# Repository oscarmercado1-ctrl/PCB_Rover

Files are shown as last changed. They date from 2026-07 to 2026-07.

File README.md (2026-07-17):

# Diseño de PCB basada en FPGA para Robot Móvil Autónomo

## Descripción

Este proyecto corresponde al diseño electrónico de una plataforma robótica móvil desarrollada como parte del curso **Diseño de Productos Electrónicos** de la **Universidad de Antioquia**.

El objetivo fue diseñar una PCB multicapa basada en una FPGA **Digilent CMOD A7 (Artix-7)** capaz de integrar sensores, actuadores, comunicaciones inalámbricas y sistemas de navegación en una arquitectura modular y escalable.

El desarrollo incluye el diseño completo del esquemático, captura jerárquica, reglas de diseño (DRC), generación del PCB de cuatro capas, análisis de costos y documentación técnica del proyecto.

---

# Características principales

- Diseño de PCB de **4 capas**.
- Arquitectura basada en FPGA **Xilinx Artix-7**.
- Comunicación inalámbrica mediante **LoRa SX1276**.
- Sistema de posicionamiento **GNSS (u-blox NEO-M9N)**.
- Sensores ambientales, inerciales y de presión.
- Comunicación mediante:
  - SPI
  - I²C
  - UART
- Control de:
  - Motores DC
  - Servomotores
  - Motor paso a paso
- Interfaz para pantalla LCD.
- Sistema de alimentación unificado a **3.3 V**.

---

# Arquitectura del sistema

La FPGA actúa como unidad central de procesamiento, implementando de forma concurrente:

- Comunicación LoRa
- Comunicación GNSS
- Lectura de sensores
- Control de motores
- Generación de señales PWM
- Procesamiento de encoders
- Gestión de la interfaz de usuario

Todo el sistema fue diseñado utilizando una arquitectura modular mediante hojas jerárquicas en Altium Designer.

---

# Componentes principales

| Componente | Función |
|---|---|
| Digilent CMOD A7 (Artix-7) | Unidad de procesamiento |
| SX1276 | Comunicación LoRa |
| u-blox NEO-M9N | Posicionamiento GNSS |
| MPU-6050 | IMU |
| Magnetómetro | Orientación |
| ADS1115 | Conversor ADC |
| Sensores de presión Honeywell MPRLS | Medición de presión |
| Encoders ópticos TCST2103 | Velocidad de motores |
| Drivers A4988 | Motor paso a paso |
| Driver L298N | Motores DC |

---

# Diseño de la PCB

El PCB fue desarrollado considerando criterios profesionales de diseño electrónico:

- PCB de cuatro capas
- Plano de tierra continuo
- Plano de alimentación dedicado
- Separación entre dominios:
  - Radiofrecuencia
  - Potencia
  - Lógica digital
- Capacitores de desacople próximos a cada circuito integrado
- Impedancia controlada para líneas RF
- Reglas de diseño compatibles con fabricantes comerciales

---

# Herramientas utilizadas

- Altium Designer
- Altium 365
- GitHub
- LaTeX
- Microsoft Excel

---

# Archivos incluidos

- Proyecto completo de Altium Designer.
- Librerías personalizadas.
- Esquemáticos jerárquicos.
- Diseño del PCB.
- Bill of Materials (BOM).
- Archivos Gerber.
- Informe técnico.
- Documentación del proyecto.

---

# Objetivos del diseño

- Integrar múltiples sensores sobre una única plataforma.
- Implementar procesamiento concurrente mediante FPGA.
- Garantizar comunicaciones inalámbricas de largo alcance.
- Facilitar futuras expansiones del sistema.
- Cumplir criterios profesionales de manufactura de PCB.

---

# Fabricación

La PCB fue diseñada para fabricación en proveedores comerciales como:

- JLCPCB
- PCBWay
- OSH Park

Características:

- 4 capas
- Espesor: 1.6 mm
- Cobre: 1 oz
- Acabado HASL libre de plomo
- Vías mínimas: 0.20 mm
- Separación mínima: 0.15 mm

---

# Autores

**Oscar David Mercado Gómez**

**Carlos Daniel Galvis Ramirez**

Ingeniería Electrónica  
Universidad de Antioquia

---

# Licencia

Este proyecto fue desarrollado con fines académicos como parte del curso **Diseño de Productos Electrónicos** de la Universidad de Antioquia.

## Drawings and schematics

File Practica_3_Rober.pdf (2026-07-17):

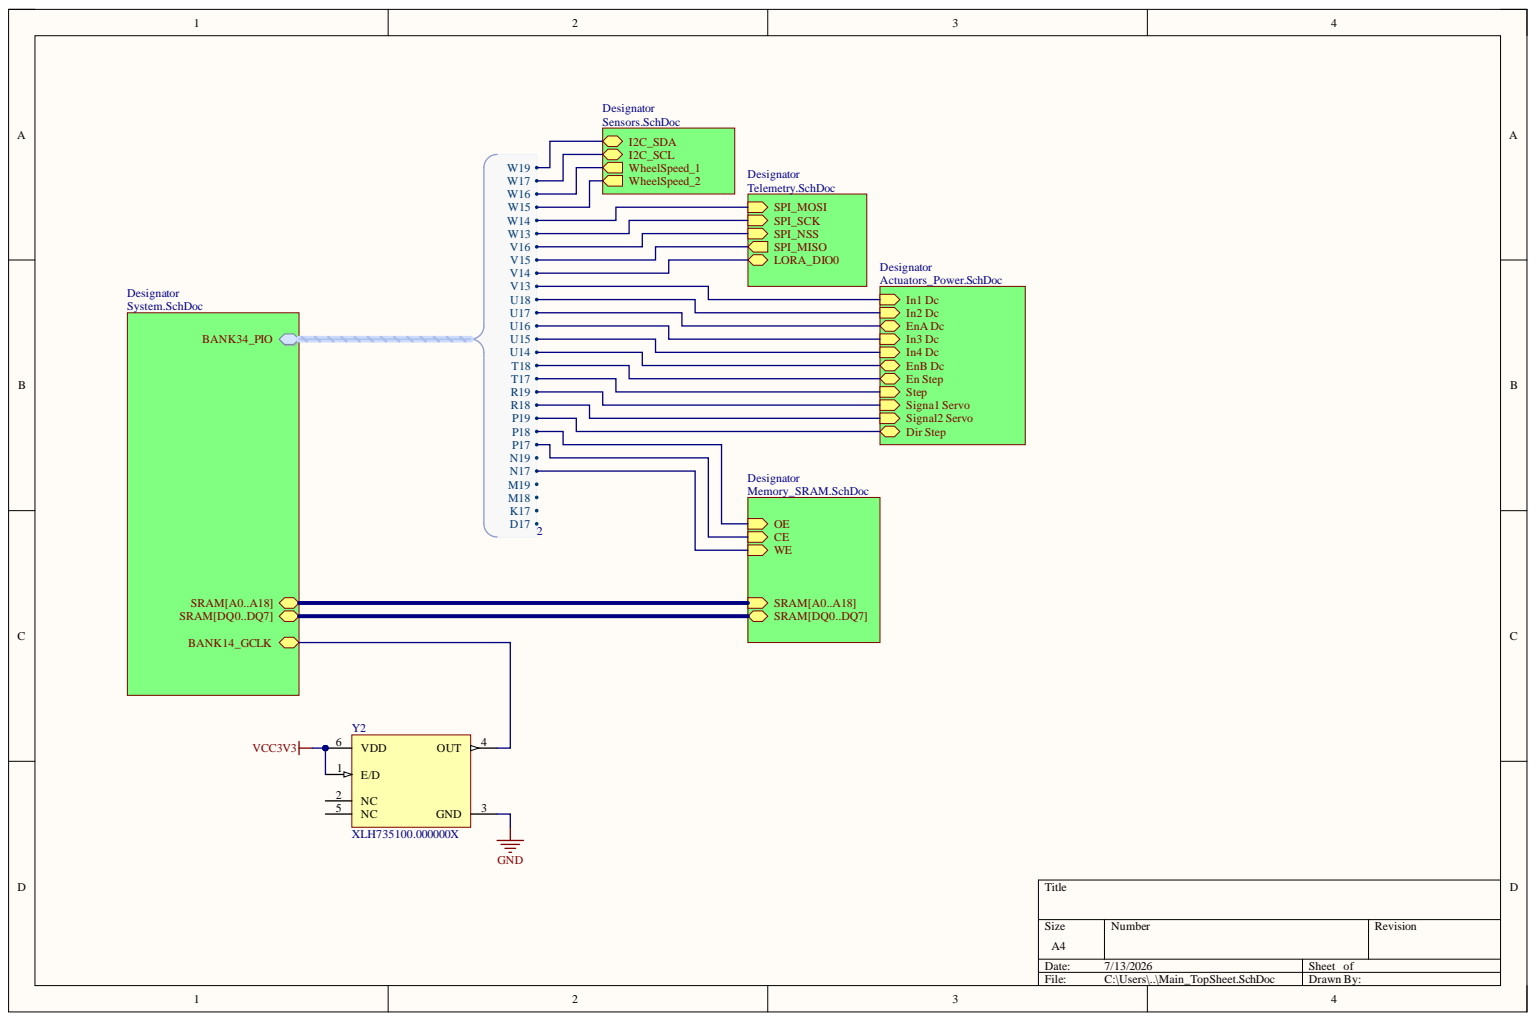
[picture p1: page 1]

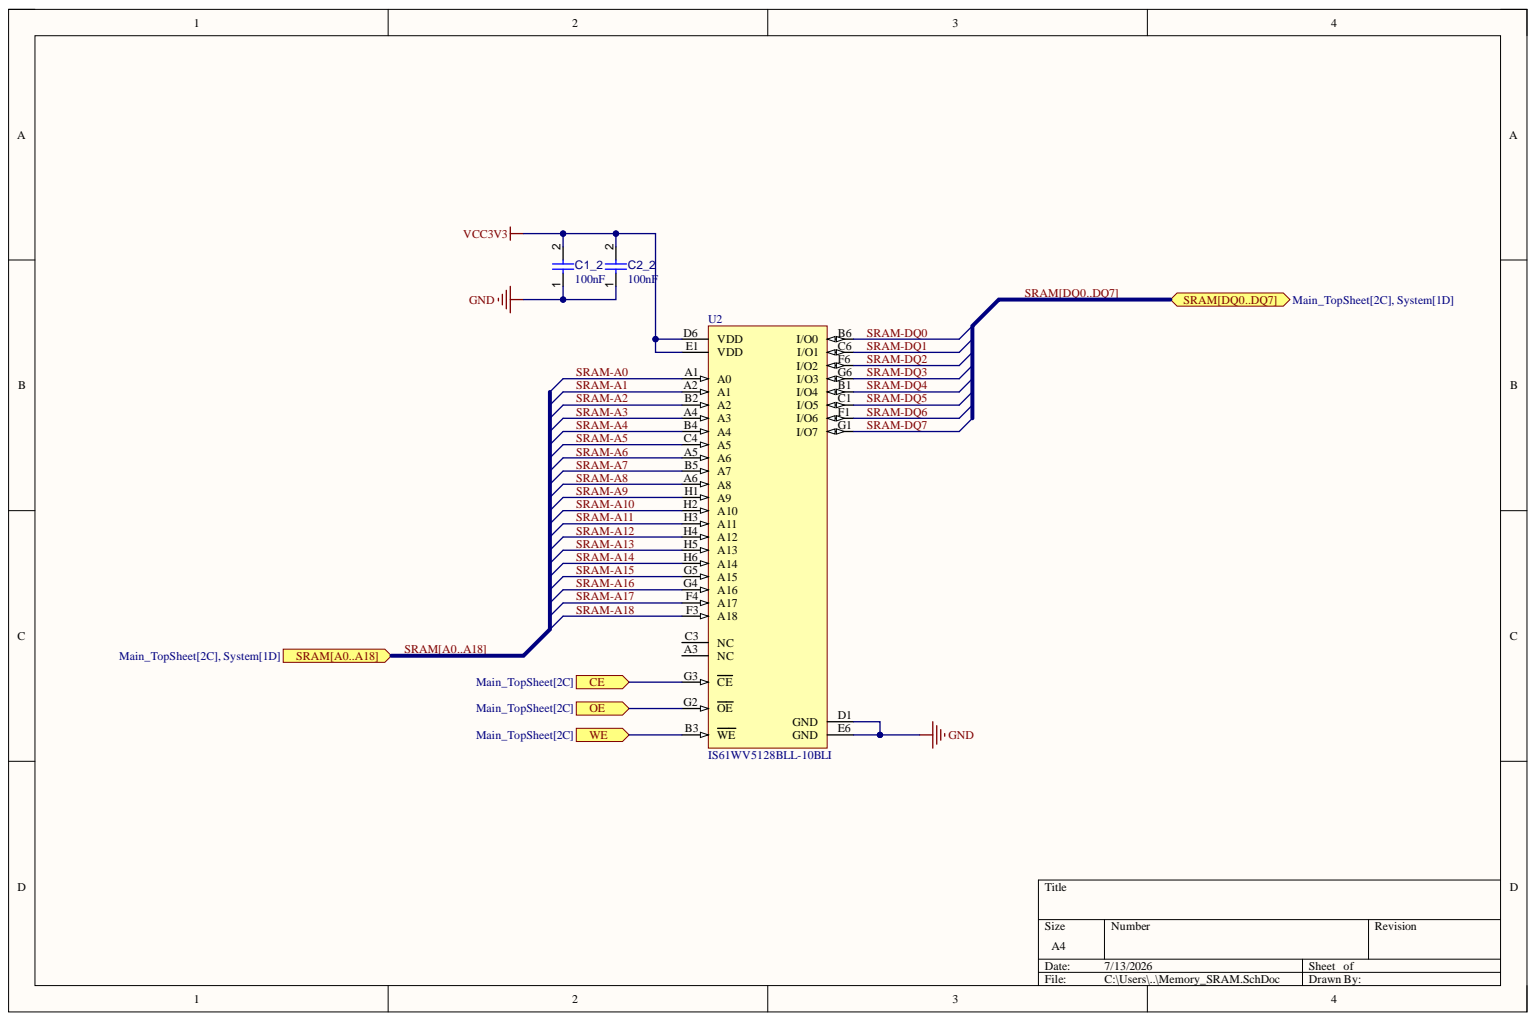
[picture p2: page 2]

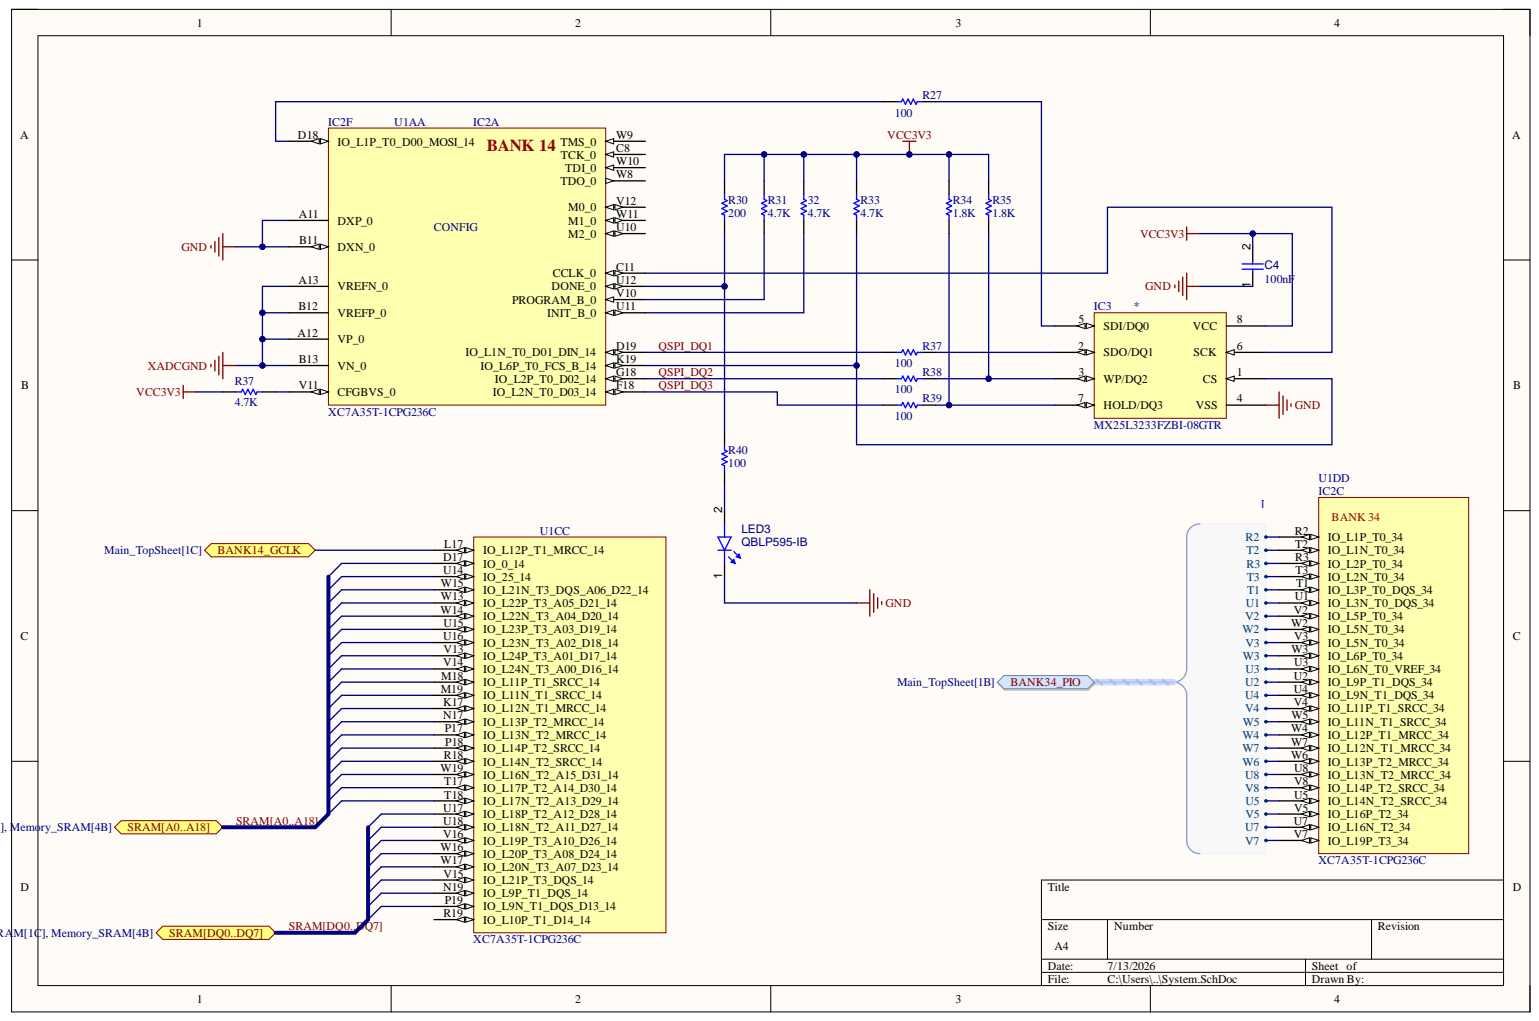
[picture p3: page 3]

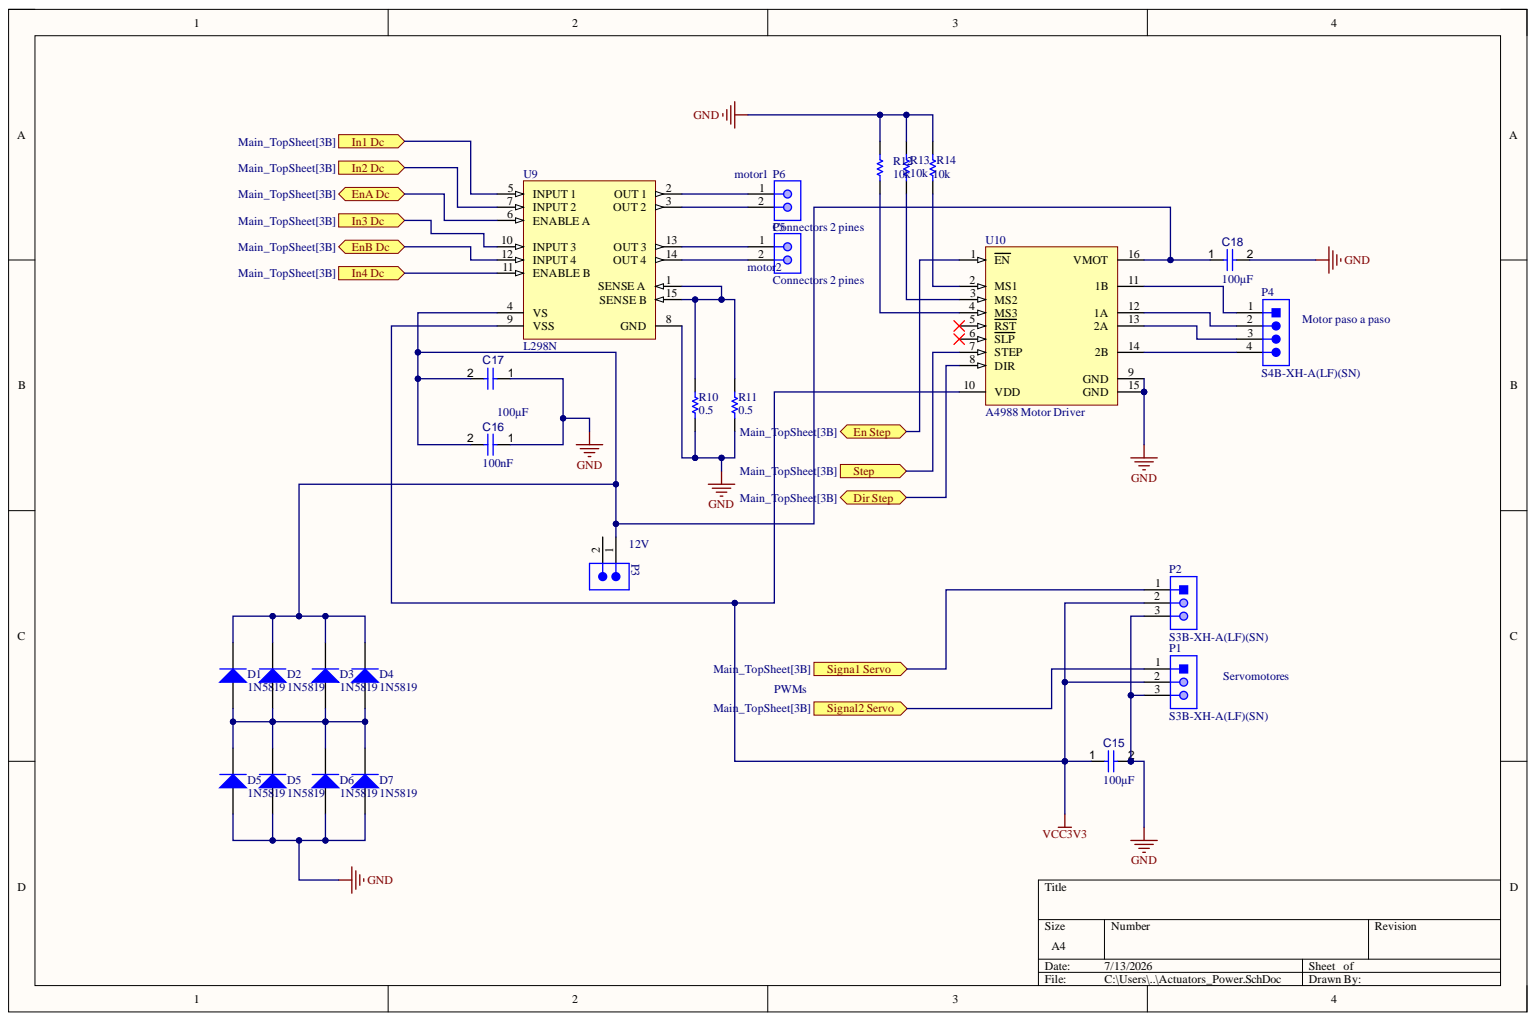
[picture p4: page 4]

MS3 4
RST 5 | 2

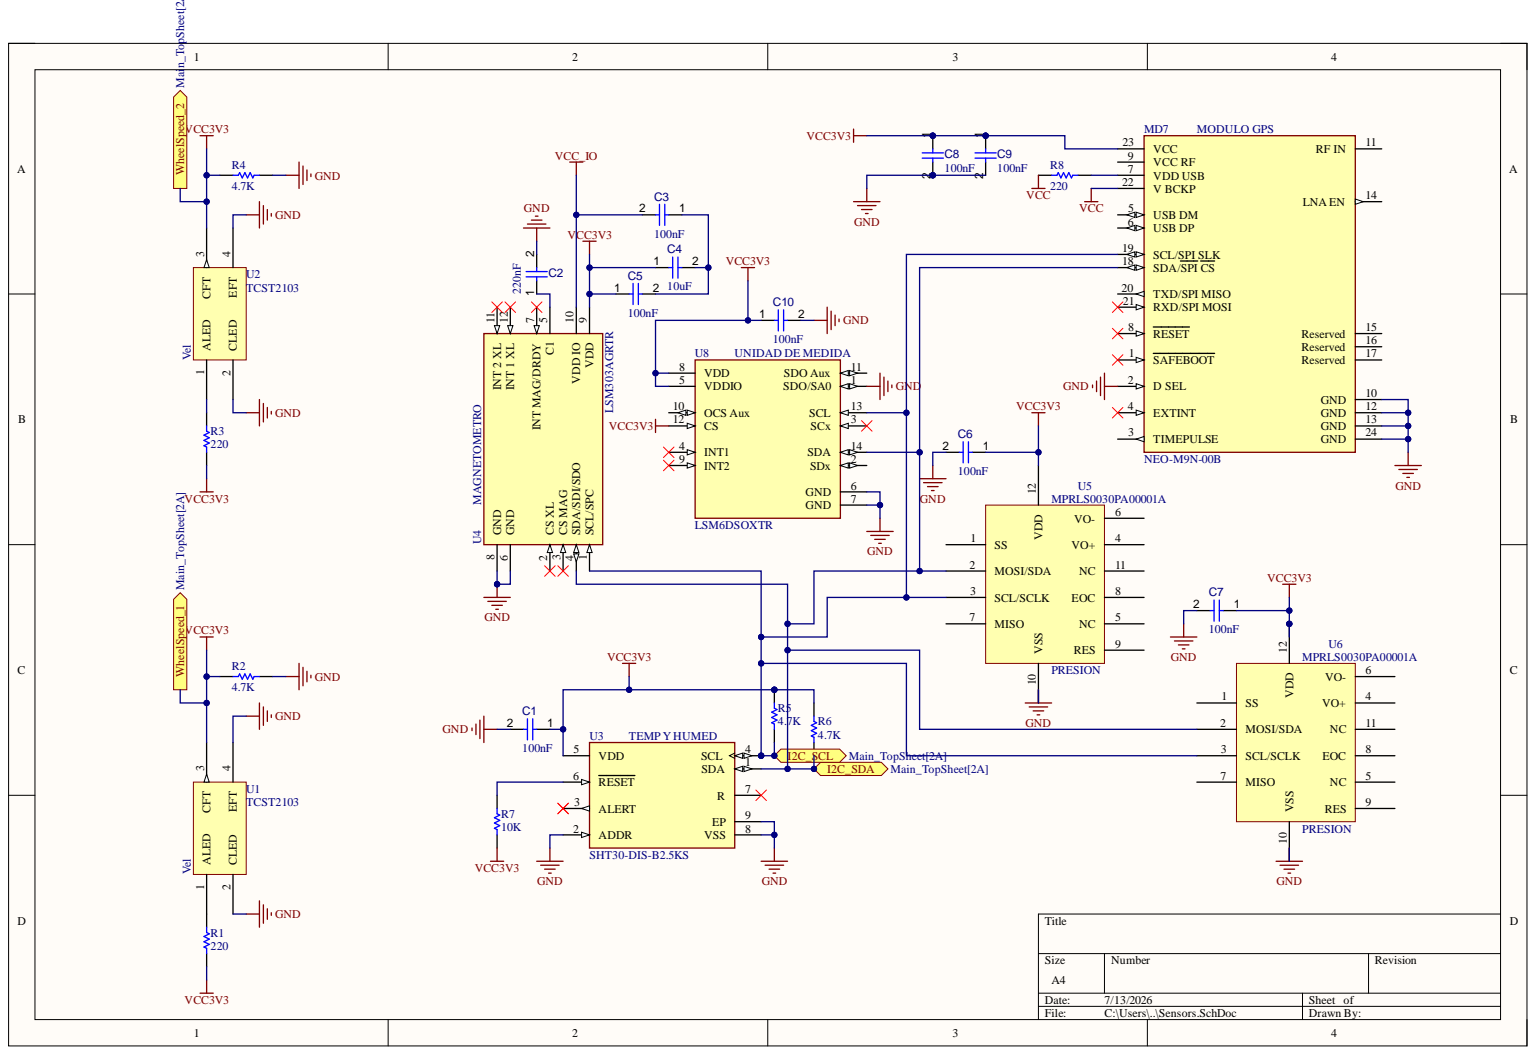
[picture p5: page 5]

INT 1 XL 12 INT 2 XL 11

VDD 9 VDD IO 10 CS MAG 3 CS XL 2

SCL/SPC 1 SDA/SDI/SDO 4

3 | MOSI/SD A N C SCL/SCL K E O C | 8

7 | MISO N C RE S

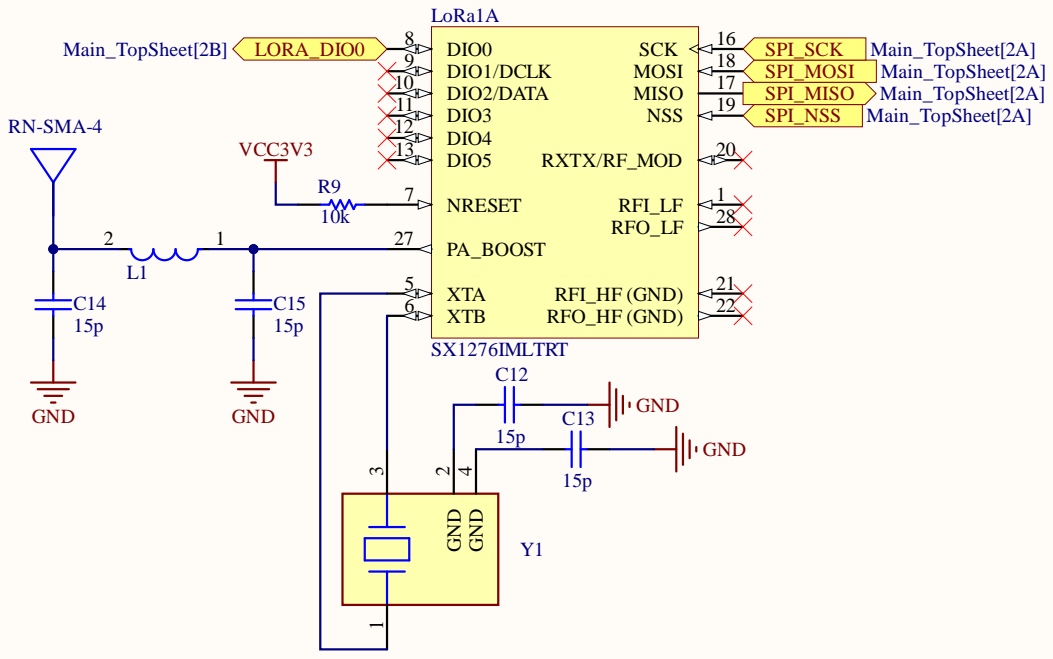
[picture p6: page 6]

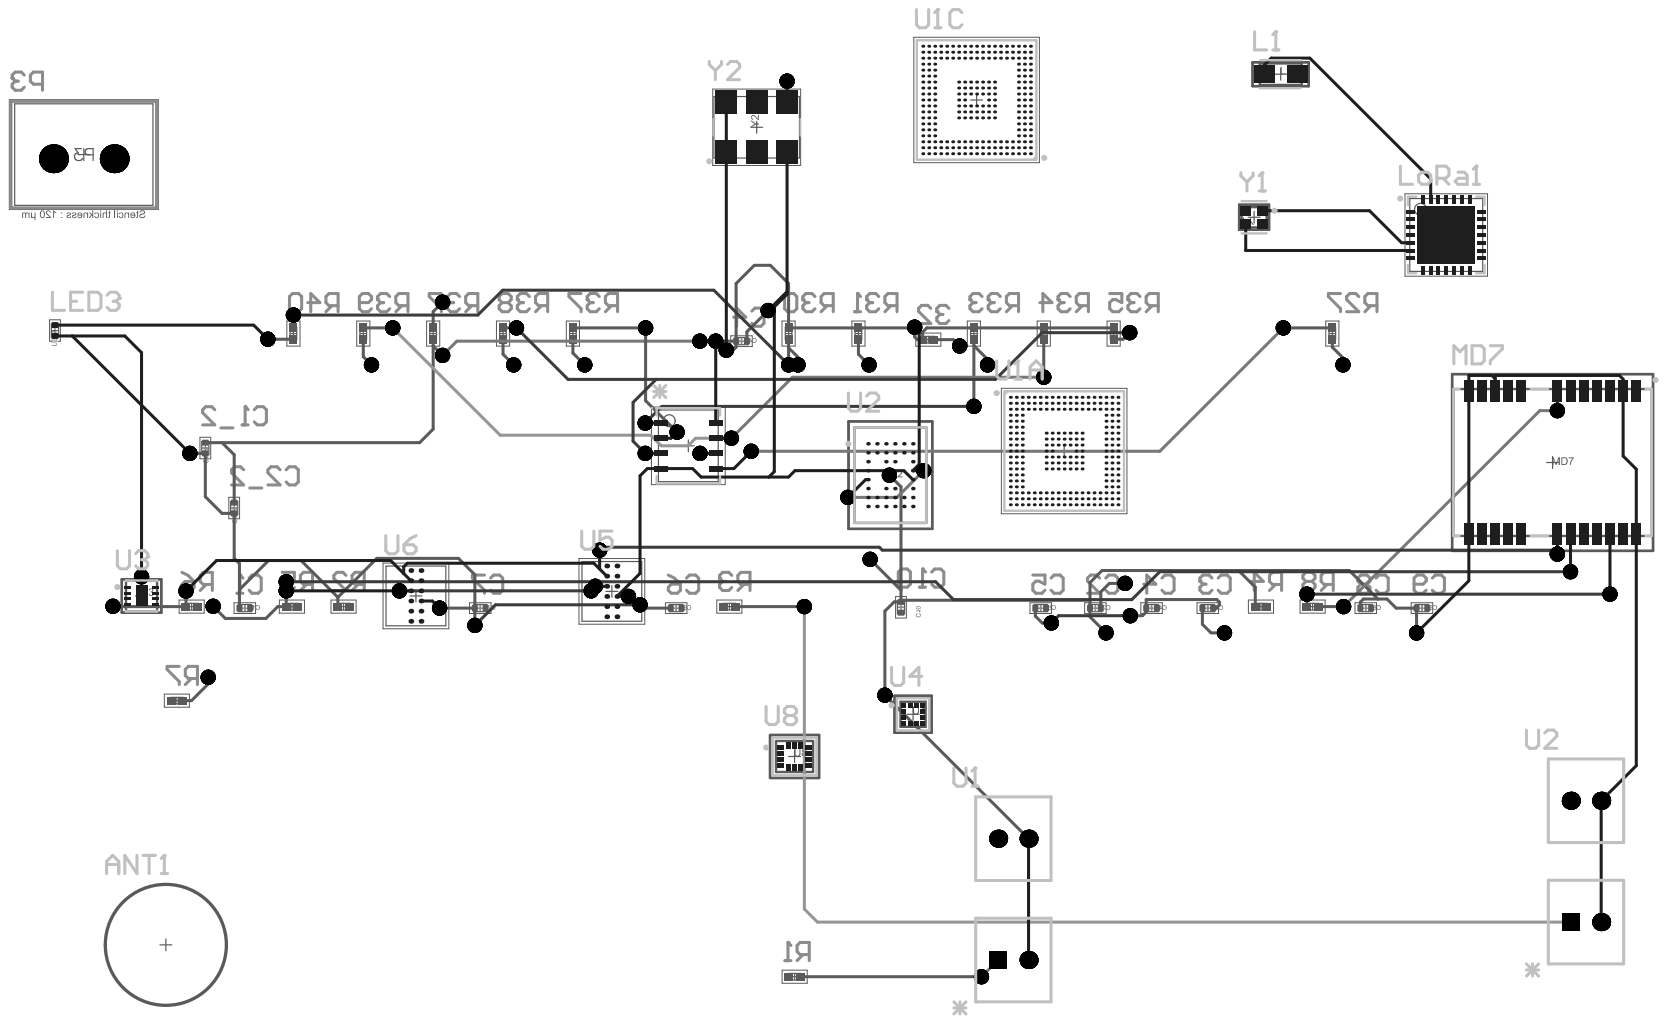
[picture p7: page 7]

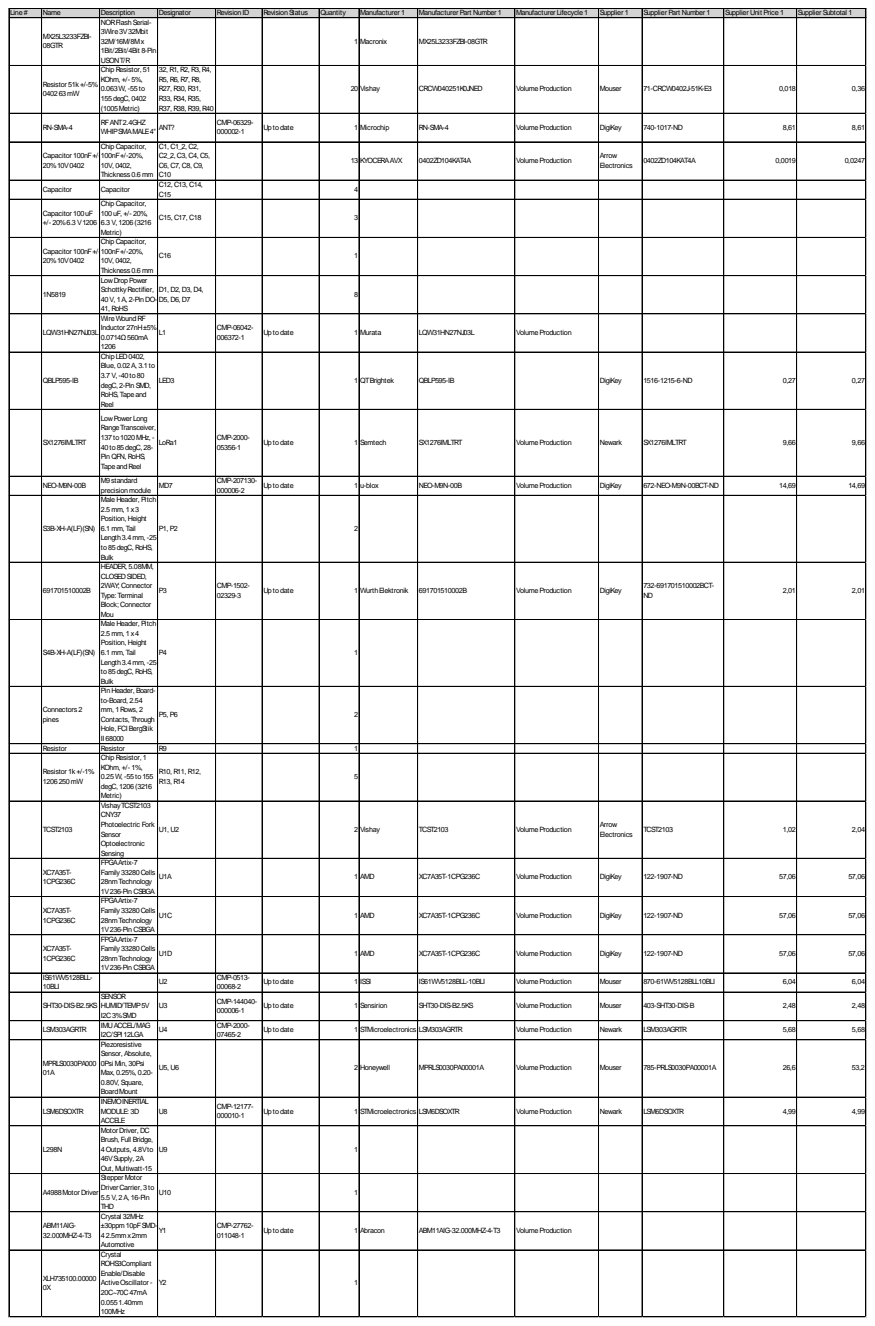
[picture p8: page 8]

Line# | Name | Description | Designator | RevisionID | RevisionStatus | Quantity | Manufacturer 1 | Manufacturer Part Number 1 | Manufacturer Lifecycle 1 | Supplier 1 | Supplier Part Number 1 | Supplier Unit Price 1 | Supplier Subtotal 1

MX25L3233FZBI-08GTR | NORFlashSerial-3Wire3V32Mbit 32M/16M/8Mx 1Bit/2Bit/4Bit 8-Pin USONT/R | | | | | 1 Macronix | MX25L3233FZBI-08GTR

Resistor 51k+/-5% 040263mW | Chip Resistor, 51 KOhm, +/- 5%, 0.063W, -55to 155degC, 0402 (1005Metric) | 32, R1, R2, R3, R4, R5, R6, R7, R8, R27, R30, R31, R33, R34, R35, R37, R38, R39, R40 | | | 20 Vishay | | CRCW040251K0JNED | VolumeProduction | Mouser | 71-CRCW0402J-51K-E3 | 0,018 | 0,36

RN-SMA-4 | RFANT2.4GHZ WHIPSMAMALE4" | ANT? | CMP-06329-000002-1 | Uptodate | | 1 Microchip | RN-SMA-4 | VolumeProduction | DigiKey | 740-1017-ND | 8,61 | 8,61

Capacitor 100nF+/-20%10V0402 | Chip Capacitor, 100nF+/-20%, 10V, 0402, Thickness0.6 mm | C1, C1_2, C2, C2_2, C3, C4, C5, C6, C7, C8, C9, C10 | | | 13 KYOCERAAVX | | 0402ZD104KAT4A | VolumeProduction | Arrow Electronics | 0402ZD104KAT4A | 0,0019 | 0,0247

Capacitor | Capacitor | C12, C13, C14, C15 | | | | 4

Capacitor 100uF +/- 20%6.3V1206 | Chip Capacitor, 100uF, +/- 20%, 6.3V, 1206(3216 Metric) | C15, C17, C18 | | | | 3

Capacitor 100nF+/-20%10V0402 | Chip Capacitor, 100nF+/-20%, 10V, 0402, Thickness0.6 mm | C16 | | | | 1

1N5819 | LowDropPower SchottkyRectifier, 40V, 1A, 2-Pin DO-41, RoHS | D1, D2, D3, D4, D5, D6, D7 | | | | 8

LQW31HN27NJ03L | WireWoundRF Inductor 27nH±5% 0.0714Ω560mA 1206 | L1 | CMP-06042-006372-1 | Uptodate | | 1 Murata | LQW31HN27NJ03L | VolumeProduction

QBLP595-IB | ChipLED0402, Blue, 0.02A, 3.1 to 3.7V, -40to80 degC, 2-PinSMD, RoHS, Tapeand Reel | LED3 | | | | 1 QTBrightek | QBLP595-IB | | DigiKey | 1516-1215-6-ND | 0,27 | 0,27

SX1276IMLTRT | LowPower Long RangeTransceiver, 137to1020MHz, -40to85degC, 28-Pin QFN, RoHS, TapeandReel | LoRa1 | CMP-2000-05356-1 | Uptodate | | 1 Semtech | SX1276IMLTRT | VolumeProduction | Newark | SX1276IMLTRT | 9,66 | 9,66

NEO-M9N-00B | M9standard precisionmodule | MD7 | CMP-207130-000006-2 | Uptodate | | 1 u-blox | NEO-M9N-00B | VolumeProduction | DigiKey | 672-NEO-M9N-00BCT-ND | 14,69 | 14,69

S3B-XH-A(LF)(SN) | Male Header, Pitch 2.5 mm, 1x3 Position, Height 6.1 mm, Tail Length3.4 mm, -25 to85degC, RoHS, Bulk | P1, P2 | | | | 2

691701510002B | HEADER, 5.08MM, CLOSEDSIDED, 2WAY; Connector Type: Terminal Block; Connector Mou | P3 | CMP-1502-02329-3 | Uptodate | | 1 WurthElektronik | 691701510002B | VolumeProduction | DigiKey | 732-691701510002BCT-ND | 2,01 | 2,01

S4B-XH-A(LF)(SN) | Male Header, Pitch 2.5 mm, 1x4 Position, Height 6.1 mm, Tail Length3.4 mm, -25 to85degC, RoHS, Bulk | P4 | | | | 1

Connectors2 pines | PinHeader, Board-to-Board, 2.54 mm, 1Rows, 2 Contacts, Through Hole, FCIBergStik II68000 | P5, P6 | | | | 2

Resistor | Resistor | R9 | | | | 1
Resistor 1k+/-1% 1206250mW | Chip Resistor, 1 KOhm, +/- 1%, 0.25W, -55to155 degC, 1206(3216 Metric) | R10, R11, R12, R13, R14 | | | | 5

TCST2103 | VishayTCST2103 CNY37 Photoelectric Fork Sensor Optoelectronic Sensing | U1, U2 | | | | 2 Vishay | TCST2103 | VolumeProduction | Arrow Electronics | TCST2103 | 1,02 | 2,04

XC7A35T-1CPG236C | FPGAArtix-7 Family 33280Cells 28nmTechnology 1V236-Pin CSBGA | U1A | | | | 1 AMD | XC7A35T-1CPG236C | VolumeProduction | DigiKey | 122-1907-ND | 57,06 | 57,06

XC7A35T-1CPG236C | FPGAArtix-7 Family 33280Cells 28nmTechnology 1V236-Pin CSBGA | U1C | | | | 1 AMD | XC7A35T-1CPG236C | VolumeProduction | DigiKey | 122-1907-ND | 57,06 | 57,06

XC7A35T-1CPG236C | FPGAArtix-7 Family 33280Cells 28nmTechnology 1V236-Pin CSBGA | U1D | | | | 1 AMD | XC7A35T-1CPG236C | VolumeProduction | DigiKey | 122-1907-ND | 57,06 | 57,06

IS61WV5128BLL-10BLI | | U2 | CMP-0513-00068-2 | Uptodate | | 1 ISSI | IS61WV5128BLL-10BLI | VolumeProduction | Mouser | 870-61WV5128BLL10BLI | 6,04 | 6,04

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

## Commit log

2026-07-05 Managed project "Practica_3_Rober" created from AD
    [Practica_3_Rober.PrjPcb]
2026-07-17 Proyecto completo
    [PCB1.PcbDoc, Practica_3_Rober.PrjPcb, System.SchDoc]
